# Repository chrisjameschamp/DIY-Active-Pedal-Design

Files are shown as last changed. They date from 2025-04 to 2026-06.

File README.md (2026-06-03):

<h2 align="center">DIY Active Pedal Design</h2>

<p align="center">
  The basic design files for my work-in-progress DIY Active Pedal.
  The majority of these parts are designed to be 3D printed.
  This project is intended to complement the much larger scale project of
  <a href="https://github.com/ChrGri" target="_blank">ChrGri</a>'s
  <a href="https://github.com/ChrGri/DIY-Sim-Racing-FFB-Pedal" target="_blank">
    DIY-Sim-Racing-FFB-Pedal
  </a>.
</p>
<div align="center">
  
  
  
  
  
  
  
  
  

</div>
<div align="center">
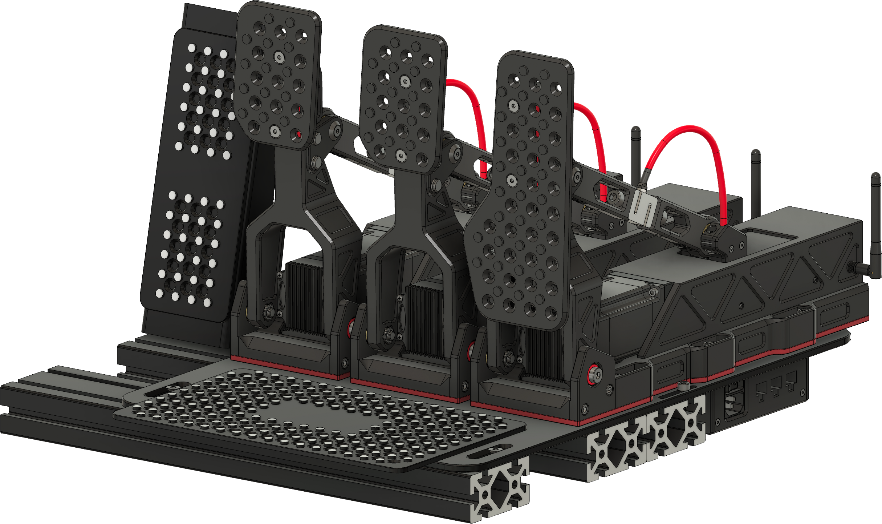
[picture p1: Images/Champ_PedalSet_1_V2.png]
Header
  
</div>

## What This Repo Includes

This repository contains the mechanical design files and build documentation for the DIY Active Pedal hardware:

- STL and STEP files for the printable and machinable pedal components
- Wiki-based build instructions, hardware references, and print guidance
- Design-file README pages for the major assemblies

This project is designed to work with the broader [DIY-Sim-Racing-FFB-Pedal](https://github.com/ChrGri/DIY-Sim-Racing-FFB-Pedal) ecosystem and the [DIY-Sim-Racing-FFB-Pedal-PCBs](https://github.com/gilphilbert/DIY-Sim-Racing-FFB-Pedal-PCBs) by gilphilbert. You will still need the required electronics, firmware/software, power supply, servo motor, linear rail, load cell, wiring, hardware, and appropriate fabrication tools to complete a working pedal.

## What Makes These Pedals Different?

Traditional sim racing pedals use springs, rubber dampers, or load cells to simulate resistance. This project takes things further by using a high-torque servo motor and a linear rail system to deliver real, programmable force feedback directly through the pedal.

What does that mean in practice?

- Feel ABS lockup through the brake pedal  
- Experience throttle kick during gear shifts or traction loss  
- Sense road texture and bumps through the pedal face  
- Adjust pedal weight, travel, and pressure curves entirely in software  
- Create and switch between custom pedal profiles for different cars

These pedals don’t just measure your input — they push back, dynamically responding to what’s happening in the simulation. Whether you’re locking up into a braking zone or driving over rumble strips, the pedals provide responsive, physical feedback.

If you're aiming to build a sim racing setup that closely mirrors a real race car experience, this project is designed to help you get there.

## Documentation

Want to build this project?  
Be sure to check out the [📖 Project Wiki](https://github.com/ChrisJamesChamp/DIY-Active-Pedal-Design/wiki/00-%E2%80%90-DIY-Active-Pedal-Build-Wiki) for:

- Print settings & material recommendations  
- Hardware lists  
- Step-by-step assembly guides 

## License

These 3D design files are licensed under a [Creative Commons BY-NC-SA 4.0 License](https://creativecommons.org/licenses/by-nc-sa/4.0/).

You may:
- Use and remix these files for **personal, non-commercial purposes**.
- Share modified versions, as long as they are also non-commercial, include credit, and use the **same license**.

You may NOT:
- Use these files or derivatives **for commercial use**.
- Re-license modified versions under more restrictive or proprietary terms.

Please credit **@ChrisJamesChamp** and link back to this repository if you use, remix, or share these designs.

##

> ⚠️ **Use at Your Own Risk**
> These design files and instructions are provided for educational and personal-use purposes only.  
> By choosing to build or modify this DIY active pedal system, you acknowledge that:
> 
> - These pedals are powered by **motorized servos**, capable of applying significant mechanical force.
> - The power supply assembly involves **AC mains voltage**, which can cause electric shock, fire, equipment damage, or serious injury if wired incorrectly.
> - Improper assembly, use, or configuration may result in **injury**, **equipment damage**, or **malfunction**.
> - You are solely responsible for ensuring **safe construction**, **appropriate materials**, and **secure electronics**.
> - I (ChrisJamesChamp) accept **no liability** for any injury, loss, or damage arising from use of these files or any derivatives thereof.
>
> **Please take all appropriate safety precautions** when working with powered mechanical and electrical systems.

##

<div align="center">
  
</div>

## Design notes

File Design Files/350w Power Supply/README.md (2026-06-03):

<h2 align="center">DIY Active Pedal Design - 350w Power Supply</h2>

<div align="center">
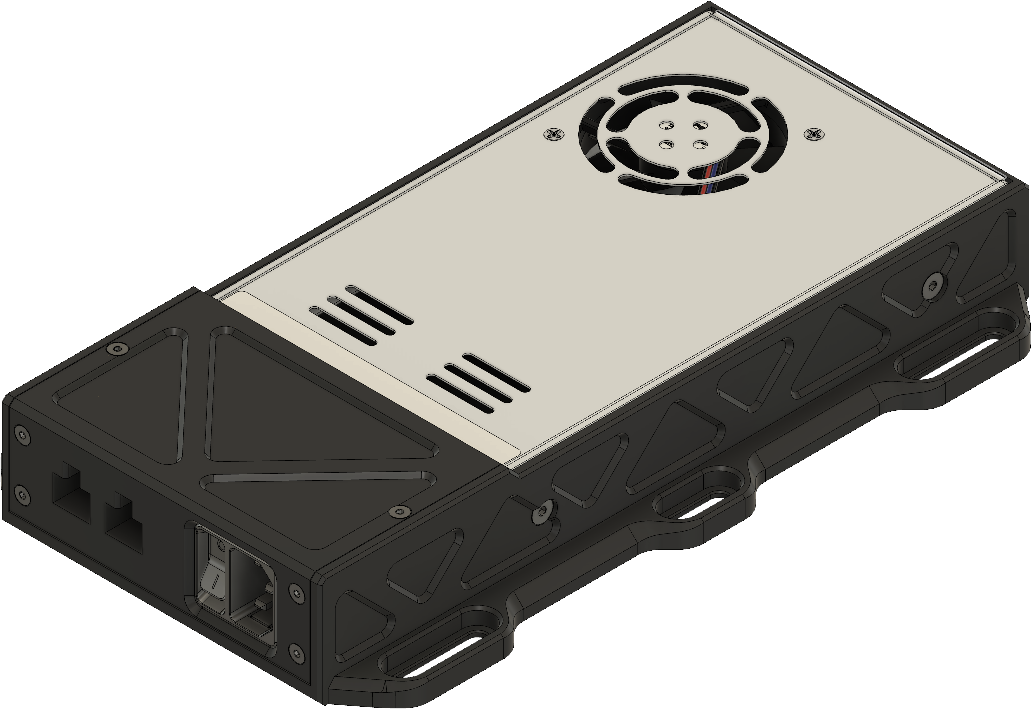
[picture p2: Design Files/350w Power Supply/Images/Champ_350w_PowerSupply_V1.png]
Header
  
</div>

## Index

- [Design](#design)
- [Print Settings](#print-settings)
- [Hardware](#hardware)
  - [Hardware List](#hardware-list)
- [Assembly](#assembly)
- [License](#license)

## Design

This power supply enclosure is completely optional to build, but it adds a few nice features: it hides the power connections, includes a power switch, and uses a standardized cable configuration that’s safe and easy to work with.

The enclosure is built around the [MEANWELL LRS-350-36](https://www.omc-stepperonline.com/lrs-350-36-mean-well-350w-36vdc-9-7a-115-230vac-enclosed-switching-power-supply-lrs-350-36). Other power supplies may work, but dimensions and specs may vary — proceed at your own risk if substituting.

This particular power supply can be used with one or two pedals.  If you are using three pedals you should use the [600w Power Supply](https://github.com/chrisjameschamp/DIY-Active-Pedal-Design/tree/main/Design%20Files/600w%20Power%20Supply) instead.

### Print Settings

This enclosure was printed on a Creality K2 Plus, but your settings will vary depending on the printer and material used. Make sure your filament is well-tuned before printing — the enclosure is large and takes time to complete.

**⚠️ Note:** The main body of the enclosure is just over **280mm wide** and may not fit on most printers. I’ve included a split version that should work on smaller beds. I haven’t tested it personally, but it should print the same.

#### Recommended Print Settings

- **Wall loops**: At least 4
- **Top layers**: 5
- **Bottom layers**: 4
- **Infill**: 20% sparse gyroid
- **If using rectangular infill**: Use 30% or higher

⚠️ **For nylon:**  
Make sure to dry your filament thoroughly before printing. Even slightly damp nylon can result in poor print quality, weak layer bonding, and rough surfaces.

For bed adhesion, use a 10mm brim and optionally apply glue stick or another adhesive. I used both, and they were essential to prevent warping.

## Hardware

The hardware used can mostly be sourced from [McMaster-Carr](https://www.mcmaster.com/).  
If you're substituting parts from your local hardware store or Amazon, be sure to double-check dimensions — they’re critical for proper fit and function.

### Hardware List

| **Item** | **Part Number** | **Qty** | **Link** |
|---|---|---|---|
| MEANWELL LRS-350-36 | LRS-350-36 | 1 | [Link](https://www.omc-stepperonline.com/lrs-350-36-mean-well-350w-36vdc-9-7a-115-230vac-enclosed-switching-power-supply-lrs-350-36) |
| IEC Connector with Power Switch | 5428N118 | 1 | [Link](https://www.mcmaster.com/5428N118/) |
| 16 Gauge Wire | N/A | As needed | [Link](https://a.co/d/feJ6wWT) |
| M3x0.5mm Heat Set Insert | 94180A333 | 6 | [Link](https://www.mcmaster.com/94180a333/) |
| M3x0.5 14mm Flat Head Screw | 92125A133 | 4 | [Link](https://www.mcmaster.com/92125A133/) |
| M3x0.5 18mm Flat Head Screw | 92125A135 | 2 | [Link](https://www.mcmaster.com/92125A135/) |
| M4x0.7 10mm Flat Head Screw | 92125A190 | 8 | [Link](https://www.mcmaster.com/92125A190/) |
| 6 Pin PCIe Extension Cable | N/A | 2 | [Link](https://a.co/d/cVutRBN) |

### Notes

1. **M4x0.7 10mm Flat Head Screw** – These should not be longer than 10mm; anything longer could damage the unit.
2. **PCIe Extension Cables** – The 350w PSU enclosure uses **2** PCIe extension cables. Additional pedal-side PCIe cables are counted separately.

## Assembly

A complete walkthrough of the assembly process can be found on the [Wiki](https://github.com/chrisjameschamp/DIY-Active-Pedal-Design/wiki/03-%E2%80%90-Power-Supply-Unit)

## License

These 3D design files are licensed under a [Creative Commons BY-NC-SA 4.0 License](https://creativecommons.org/licenses/by-nc-sa/4.0/).

You may:
- Use and remix these files for **personal, non-commercial purposes**.
- Share modified versions, as long as they are also non-commercial, include credit, and use the **same license**.

You may NOT:
- Use these files or derivatives **for commercial use**.
- Re-license modified versions under more restrictive or proprietary terms.

Please credit **@ChrisJamesChamp** and link back to this repository if you use, remix, or share these designs.

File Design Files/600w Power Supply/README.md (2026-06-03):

<h2 align="center">DIY Active Pedal Design - 600w Power Supply</h2>

<div align="center">
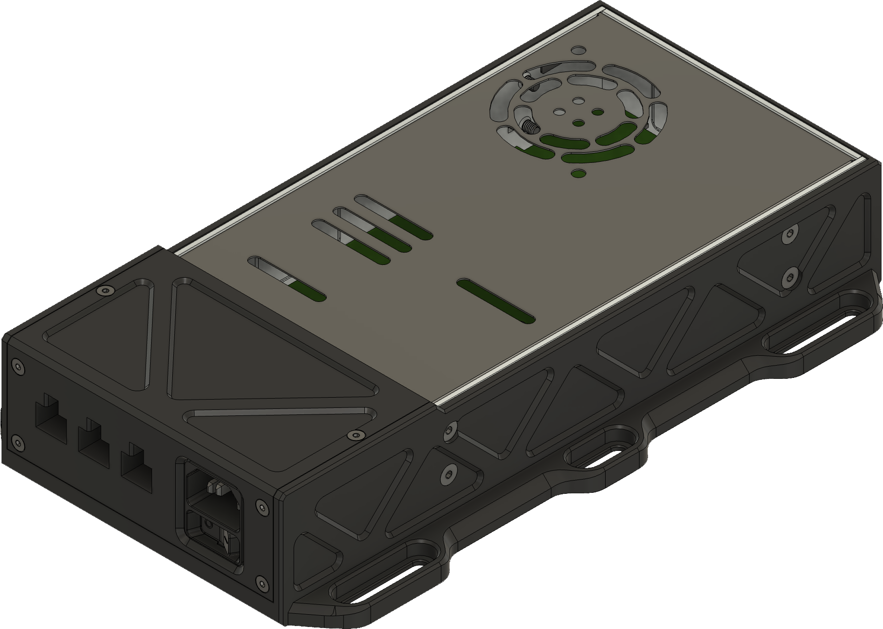
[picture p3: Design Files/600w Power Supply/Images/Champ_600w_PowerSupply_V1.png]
Header
  
</div>

## Index

- [Design](#design)
- [Print Settings](#print-settings)
- [Hardware](#hardware)
  - [Hardware List](#hardware-list)
- [Assembly](#assembly)
- [License](#license)

## Design

This power supply enclosure is completely optional to build, but it adds a few nice features: it hides the power connections, includes a power switch, and uses a standardized cable configuration that’s safe and easy to work with.

The enclosure is built around the [MEANWELL LRS-600-36](https://www.omc-stepperonline.com/lrs-600-36-mean-well-597-6w-36vdc-16-6a-115-230vac-enclosed-switching-power-supply-lrs-600-36). Other power supplies may work, but dimensions and specs may vary — proceed at your own risk if substituting.

This particular power supply can be used with up to three pedals.  However the 600w PSU might be a bit overkill for one or two pedals; consider using the [350w Power Supply](https://github.com/chrisjameschamp/DIY-Active-Pedal-Design/tree/main/Design%20Files/350w%20Power%20Supply) instead.

### Print Settings

This enclosure was printed on a Creality K2 Plus, but your settings will vary depending on the printer and material used. Make sure your filament is well-tuned before printing — the enclosure is large and takes time to complete.

**⚠️ Note:** The main body of the enclosure is just over **280mm wide** and may not fit on most printers. I’ve included a split version that should work on smaller beds. I haven’t tested it personally, but it should print the same.

#### Recommended Print Settings

- **Wall loops**: At least 4
- **Top layers**: 5
- **Bottom layers**: 4
- **Infill**: 20% sparse gyroid
- **If using rectangular infill**: Use 30% or higher

⚠️ **For nylon:**  
Make sure to dry your filament thoroughly before printing. Even slightly damp nylon can result in poor print quality, weak layer bonding, and rough surfaces.

For bed adhesion, use a 10mm brim and optionally apply glue stick or another adhesive. I used both, and they were essential to prevent warping.

## Hardware

The hardware used can mostly be sourced from [McMaster-Carr](https://www.mcmaster.com/).  
If you're substituting parts from your local hardware store or Amazon, be sure to double-check dimensions — they’re critical for proper fit and function.

### Hardware List

| **Item** | **Part Number** | **Qty** | **Link** |
|---|---|---|---|
| MEANWELL LRS-600-36 | LRS-600-36 | 1 | [Link](https://www.omc-stepperonline.com/lrs-600-36-mean-well-597-6w-36vdc-16-6a-115-230vac-enclosed-switching-power-supply-lrs-600-36) |
| IEC Connector with Power Switch | 5428N111 | 1 | [Link](https://www.mcmaster.com/5428N111/) |
| 16 Gauge Wire | N/A | As needed | [Link](https://a.co/d/feJ6wWT) |
| M3x0.5mm Heat Set Insert | 94180A333 | 6 | [Link](https://www.mcmaster.com/94180a333/) |
| M3x0.5 14mm Flat Head Screw | 92125A133 | 4 | [Link](https://www.mcmaster.com/92125A133/) |
| M3x0.5 18mm Flat Head Screw | 92125A135 | 2 | [Link](https://www.mcmaster.com/92125A135/) |
| M4x0.7 10mm Flat Head Screw | 92125A190 | 10 | [Link](https://www.mcmaster.com/92125A190/) |
| 6 Pin PCIe Extension Cable | N/A | 3 | [Link](https://a.co/d/cVutRBN) |

### Notes

1. **M4x0.7 10mm Flat Head Screw** – These should not be longer than 10mm; anything longer could damage the unit.
2. **PCIe Extension Cables** – The 600w PSU enclosure uses **3** PCIe extension cables. Additional pedal-side PCIe cables are counted separately.

## Assembly

A complete walkthrough of the assembly process can be found on the [Wiki](https://github.com/chrisjameschamp/DIY-Active-Pedal-Design/wiki/03-%E2%80%90-Power-Supply-Unit)

## License

These 3D design files are licensed under a [Creative Commons BY-NC-SA 4.0 License](https://creativecommons.org/licenses/by-nc-sa/4.0/).

You may:
- Use and remix these files for **personal, non-commercial purposes**.
- Share modified versions, as long as they are also non-commercial, include credit, and use the **same license**.

You may NOT:
- Use these files or derivatives **for commercial use**.
- Re-license modified versions under more restrictive or proprietary terms.

Please credit **@ChrisJamesChamp** and link back to this repository if you use, remix, or share these designs.

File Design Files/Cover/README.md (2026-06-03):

<h2 align="center">DIY Active Pedal Design - Cover</h2>
<div align="center">
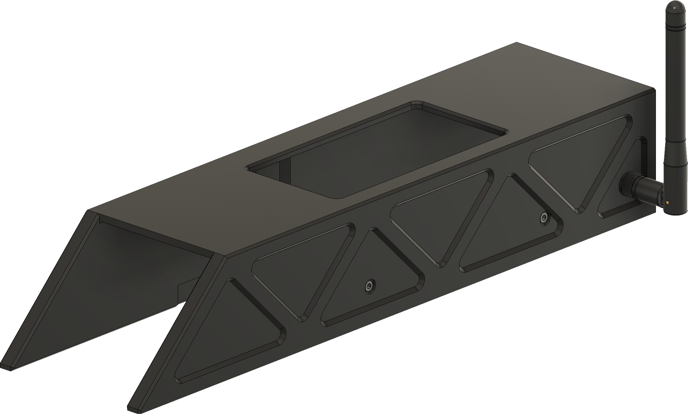
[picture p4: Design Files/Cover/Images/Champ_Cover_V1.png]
Header
  
</div>

## Index

- [Design](#design)
- [3D Printing](#3d-printing)
   - [Material Options](#material-options)
   - [Print Settings](#print-settings)
- [Hardware](#hardware)
   - [Hardware List](#hardware-list)
- [Assembly](#assembly)
- [License](#license)

## Design

The cover is more aesthetics than anything, however it is helpful in reducing the amount of dust and debris that will get into the linear rail which needs to stay clean and lubricated.

## 3D Printing

The cover is designed to be 3d printed, it could be CNC machined as well, although it would probably not be super easy and/or cheap.  If it were to be CNC machined however, there are a lot of areas that could be simplified or adjusted with drill taps to eliminate the use of some hardware.

### Material Options

I’ve only tested this part printed in [Fiberon's PETG-CF](https://a.co/d/dX2OyLc).

The **Cover** is not structural and does not need to be printed in nylon.

### Print Settings

The cover was printed on a Creality K2 Plus, but print settings will vary depending on your printer and material.

**⚠️ Note:** The cover is just over **280mm wide** and may not fit on most printers. I’ve included a split version that should work on smaller beds. I haven’t tested it personally, but it should print the same.

#### Recommended Print Settings

- **Wall loops**: At least 3
- **Top layers**: 4
- **Bottom layers**: 3
- **Infill**: 15% sparse gyroid
- **If using rectangular infill**: Use 20% or higher

## Hardware

The hardware I used can mostly be sourced from [McMaster-Carr](https://www.mcmaster.com/).  
If you're substituting parts from your local hardware store or Amazon, be sure to double-check dimensions — they're critical for fit and function.

### Hardware List

| **Item** | **Part Number** | **Qty** | **Link** |
|---|---|---|---|
| M2.5x0.4 6mm Socket Head Screw  | 91292A010 | 4 | [Link](https://www.mcmaster.com/91292A010/) |
| M3x0.5mm Heat Set Insert | 94180A333 | 2 | [Link](https://www.mcmaster.com/94180A333/) |
| M3x0.5 16mm Socket Head Screw | 91292A115 | 2 | [Link](https://www.mcmaster.com/91292A115/) |
| Coax Antenna Cable | N/A | 1 | [Link](https://a.co/d/crMru0R) |

## Assembly

A complete walkthrough of the assembly process can be found on the [Slider Cover wiki page](https://github.com/chrisjameschamp/DIY-Active-Pedal-Design/wiki/09-%E2%80%90-Slider-Cover).

## License

These 3D design files are licensed under a [Creative Commons BY-NC-SA 4.0 License](https://creativecommons.org/licenses/by-nc-sa/4.0/).

You may:
- Use and remix these files for **personal, non-commercial purposes**.
- Share modified versions, as long as they are also non-commercial, include credit, and use the **same license**.

You may NOT:
- Use these files or derivatives **for commercial use**.
- Re-license modified versions under more restrictive or proprietary terms.

Please credit **@ChrisJamesChamp** and link back to this repository if you use, remix, or share these designs.

##

<div align="center">
  
</div>

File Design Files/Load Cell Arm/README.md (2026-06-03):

<h2 align="center">DIY Active Pedal Design - Load Cell Arm</h2>
<div align="center">
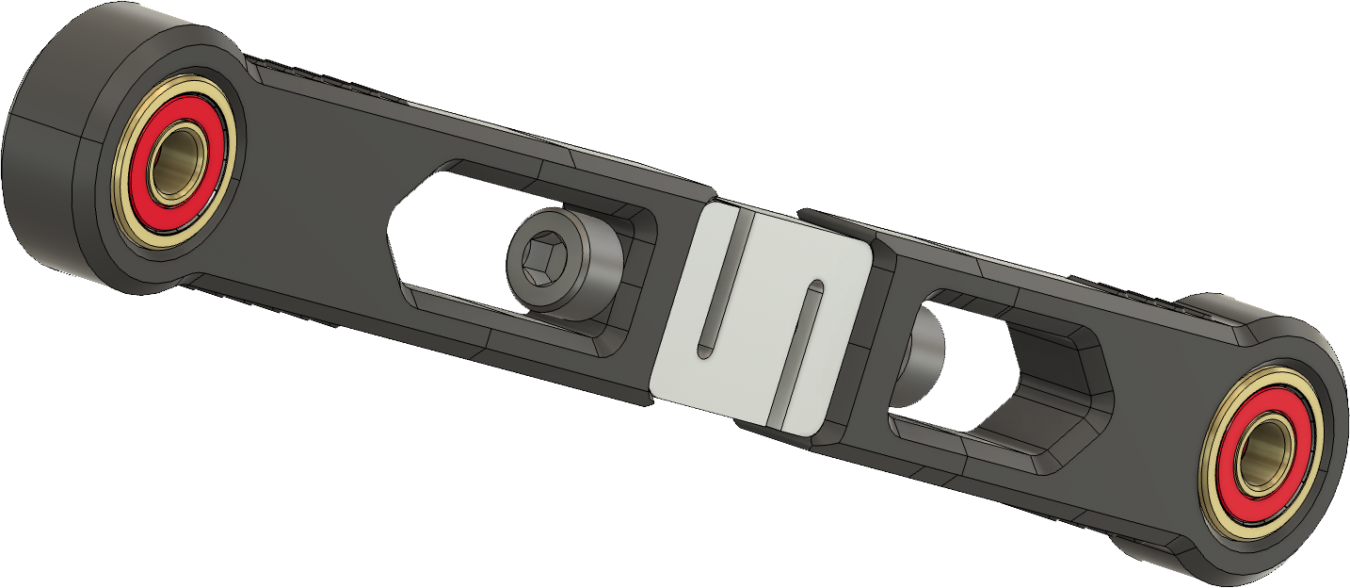
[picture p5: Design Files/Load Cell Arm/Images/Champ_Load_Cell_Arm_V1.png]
Header
  
</div>

## Index

- [Design](#design)
- [3D Printing](#3d-printing)
   - [Material Options](#material-options)
   - [Print Settings](#print-settings)
- [Hardware](#hardware)
   - [Hardware List](#hardware-list)
- [Assembly](#assembly)
- [License](#license)

## Design

The load cell arm connects the pedal arm to the slider and is the primary component for transferring forces between the pedal arm and the servo motor.

## 3D Printing

The arm is designed to be 3D printed, though it is one of the few parts that would **greatly benefit** from being CNC machined due to the forces involved.

### Material Options

This part has only been tested using [Fiberon's PPS-CF](https://a.co/d/0nK6oxm).

While PPS is known for its **high temperature resistance**, it also offers excellent stiffness with minimal deformation, making it ideal for this application. Nylon may work, but it tends to flex more under load. Less deformation in this part means more accurate and precise force transfer to the load cell.

### Print Settings

The arm was printed on a Creality K2 Plus, but settings may vary depending on your printer and chosen material.

#### Recommended Print Settings

- **Wall loops**: At least 10
- **Top layers**: 12
- **Bottom layers**: 10
- **Infill**: 30% sparse gyroid
- **If using rectangular infill**: Use 40% or higher

⚠️ For PPS:
Thoroughly dry your filament before printing. Even slightly damp PPS will print poorly, resulting in weak layer adhesion and rough surface quality.

## Hardware

The hardware I used can mostly be sourced from [McMaster-Carr](https://www.mcmaster.com/).  
If you're substituting parts from your local hardware store or Amazon, be sure to double-check dimensions — they're critical for fit and function.

### Hardware List

| **Item** | **Part Number** | **Qty** | **Link** |
|---|---|---|---|
| Pressure Sensor S Load Cell Weight Sensor(200KG) | DYLY-107 | 1 | [Link](https://a.co/d/eEIK39s) |
| M8x1.25 18mm Socket Head Cap Screw | 91292A080  | 2 | [Link](https://www.mcmaster.com/91292A080/) |
| 608ZZ Bearing | 608ZZ | 4 | [Link](https://a.co/d/8xCCTFy) |

### Notes

1. **Pressure Sensor** – I used the 200KG variant, which is the highest recommended. Anything between 100KG and 200KG should work well depending on your force preference.

## Assembly

A complete walkthrough of the assembly process can be found on the [Load Cell Arm wiki page](https://github.com/chrisjameschamp/DIY-Active-Pedal-Design/wiki/07-%E2%80%90-Load-Cell-Arm).

## License

These 3D design files are licensed under a [Creative Commons BY-NC-SA 4.0 License](https://creativecommons.org/licenses/by-nc-sa/4.0/).

You may:
- Use and remix these files for **personal, non-commercial purposes**.
- Share modified versions, as long as they are also non-commercial, include credit, and use the **same license**.

You may NOT:
- Use these files or derivatives **for commercial use**.
- Re-license modified versions under more restrictive or proprietary terms.

Please credit **@ChrisJamesChamp** and link back to this repository if you use, remix, or share these designs.

##

<div align="center">
  
</div>

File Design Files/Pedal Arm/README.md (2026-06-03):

<h2 align="center">DIY Active Pedal Design - Pedal Arm</h2>
<div align="center">
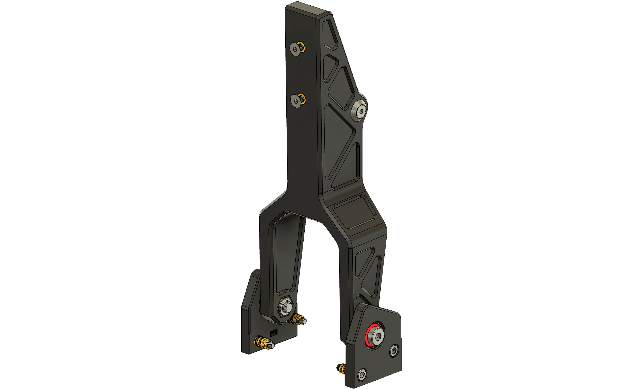
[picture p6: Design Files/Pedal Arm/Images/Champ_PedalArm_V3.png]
Header
  
</div>

## Index

- [Design](#design)
- [3D Printing](#3d-printing)
   - [Material Options](#material-options)
   - [Print Settings](#print-settings)
- [Hardware](#hardware)
   - [Hardware List](#hardware-list)
- [Assembly](#assembly)
- [License](#license)

## Design

This is the third design iteration of the Pedal Arm. The first version had mounting brackets approximately 25mm lower, which increased travel but reduced usable servo force. Since that much travel isn’t necessary, the brackets were moved upward in later revisions — nearly doubling the effective braking force the servos can handle. The current version also includes additional stiffness improvements over the earlier arms.

## 3D Printing

The arm is designed to be 3d printed, it could be CNC machined as well, although it would probably not be super easy and/or cheap.  If it were to be CNC machined however, there are a lot of areas that could be simplified or adjusted with drill taps to eliminate the use of some hardware.

### Material Options

I’ve only tested this part printed in eSun’s [ePA-CF](https://a.co/d/0XDH10W), an 80/20 nylon-carbon fiber composite with excellent strength, layer adhesion, and added rigidity from the carbon fiber. It also has relatively high tensile strength.

You could try pure nylon, although it might be too flexible.

More affordable options like PETG+CF or ABS+CF composites may work as well. While they likely have enough strength in the XY axis (which is how the part is oriented for printing), I’m less confident in their Z-axis strength due to weaker layer bonding.

Some users in the DIY FFB Pedal Discord have reported success with PLA+ or regular PETG. I haven’t tested these myself, and I’d be cautious about PLA+’s long-term durability.

### Print Settings

The pedal arm was printed on a Creality K2 Plus, but print settings will vary depending on your printer and material. Make sure your filament and printer are well-tuned before attempting a full print — it’s a large part and can take quite a while.

Don’t do what I did and print seven of them while dialing in settings 😅

#### Recommended Print Settings

- **Wall loops**: At least 10
- **Top layers**: 12
- **Bottom layers**: 10
- **Infill**: 30% sparse gyroid
- **If using rectangular infill**: Use 40% or higher

⚠️ For nylon:
Thoroughly dry your filament before printing. Even slightly damp nylon will print poorly, resulting in weak layer adhesion and rough surface quality.

Due to the high wall/infill density, use a brim (10mm recommended) and possibly glue stick or other adhesion aid. I used both, and they were necessary to prevent warping.

## Hardware

The hardware I used can mostly be sourced from [McMaster-Carr](https://www.mcmaster.com/).  
If you're substituting parts from your local hardware store or Amazon, be sure to double-check dimensions — they're critical for fit and function.

### Hardware List

| **Item** | **Part Number** | **Qty** | **Link** |
|---|---|---|---|
| M8x1.25 25mm Hex Cap Head Screw | 92095A286 | 2 | [Link](https://www.mcmaster.com/92095A286/) |
| M8 Nylon Locking Nut | 93625A300 | 2 | [Link](https://www.mcmaster.com/93625A300/) |
| M5x0.8mm Heat Set Insert | 94180A363 | 6 | [Link](https://www.mcmaster.com/94180A363/) |
| M3 Square Nut | 97258A101 | 2 | [Link](https://www.mcmaster.com/97258A101/) |
| M5x0.8 14mm Socket Head Screw | 91292A058 | 4 | [Link](https://www.mcmaster.com/91292A058/) |
| M3x0.5 16mm Flat Head Screw | 92125A134 | 2 | [Link](https://www.mcmaster.com/92125A134/) |
| M5x0.8 16mm Flat Head Screw | 92125A212 | 2 | [Link](https://www.mcmaster.com/92125A212/) |
| M5 Steel Finish Washer | 98472A300 | 2 | [Link](https://www.mcmaster.com/98472A300/) |
| M5x0.8 12mm Flat Head Screw | 92125A210 | 2 | [Link](https://www.mcmaster.com/92125A210/) |
| 8mm OD, 4.2mm ID, 30mm Spacer | 92871A212 | 1 | [Link](https://www.mcmaster.com/92871A212/) |
| 608ZZ Bearing | 608ZZ | 2 | [Link](https://a.co/d/8xCCTFy) |

### Notes

1. **M5x0.8mm Heat Set Insert** – The side mounts use 4 x M5x0.8mm Heat Set Insert. The front-facing holes of the pedal arm use 2 x M5x0.8mm Heat Set Insert.
2. **8mm OD Spacer** – This needs to be **tapped on both sides** for M5x0.8 threads.

## Assembly

Complete walkthroughs of the assembly process can be found on the [Pedal Arm wiki page](https://github.com/chrisjameschamp/DIY-Active-Pedal-Design/wiki/06-%E2%80%90-Pedal-Arm) and [Arm Connection wiki page](https://github.com/chrisjameschamp/DIY-Active-Pedal-Design/wiki/10-%E2%80%90-Arm-Connection).

## License

These 3D design files are licensed under a [Creative Commons BY-NC-SA 4.0 License](https://creativecommons.org/licenses/by-nc-sa/4.0/).

You may:
- Use and remix these files for **personal, non-commercial purposes**.
- Share modified versions, as long as they are also non-commercial, include credit, and use the **same license**.

You may NOT:
- Use these files or derivatives **for commercial use**.
- Re-license modified versions under more restrictive or proprietary terms.

Please credit **@ChrisJamesChamp** and link back to this repository if you use, remix, or share these designs.

##

<div align="center">
  
</div>

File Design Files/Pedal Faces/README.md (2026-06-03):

<h2 align="center">DIY Active Pedal Design - Pedal Faces</h2>
<div align="center">
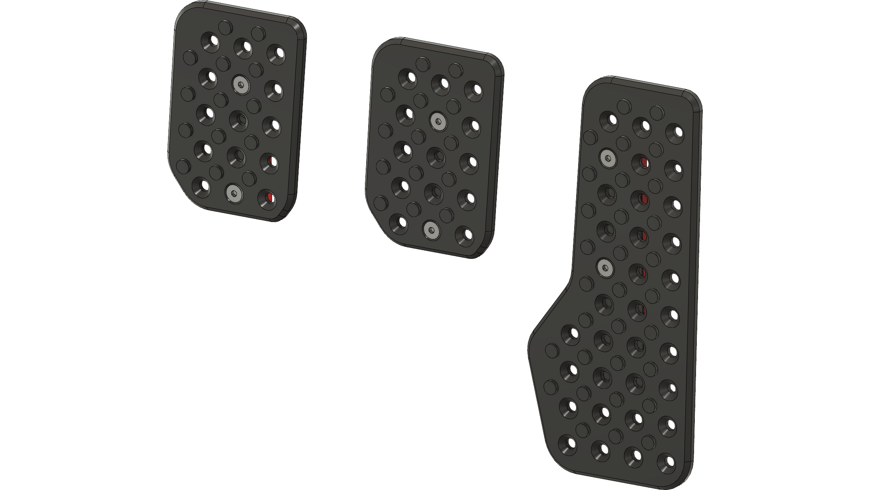
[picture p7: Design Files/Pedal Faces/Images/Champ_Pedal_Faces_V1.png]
Header
  
</div>

## Index

- [Design](#design)
- [3D Printing](#3d-printing)
   - [Material Options](#material-options)
   - [Print Settings](#print-settings)
- [Hardware](#hardware)
   - [Hardware List](#hardware-list)
- [Assembly](#assembly)
- [License](#license)

## Design

The pedal faces are designed to match my existing dead pedal and heel plate from [Pedal Haus](http://www.pedalhaus.com), which produces pedals and accessories for most BMW models.  
Each pedal face consists of **three parts**: the faceplate, the mounting bracket, and a cosmetic beauty ring.

There are two distinct pedal face shapes and three mounting brackets. The **throttle pedal** is larger and uses its own mounting bracket. The **brake and clutch pedals** share the same face, but use different mounting brackets. This difference ensures that when all three pedal assemblies are mounted equidistant from one another, the spacing between pedals remains visually and functionally consistent.

If you're building only a throttle and brake pedal setup, you can choose either the **brake** or **clutch** bracket for the brake pedal. The **clutch bracket** increases the spacing between the pedals, while the **brake bracket** decreases it.  
Which one you use is entirely a matter of personal preference.

## 3D Printing

These parts are designed for 3D printing, though the faceplates are one of the few components that could benefit significantly from being **CNC machined** for a more polished and professional finish. I eventually plan to machine and anodize mine to match the rest of my Pedal Haus components.

### Material Options

The pedal face has been tested with [Fiberon's PPS-CF](https://a.co/d/0nK6oxm), though it should also work well with eSun’s [ePA-CF](https://a.co/d/0XDH10W).

- **Pedal Mount**: Should be printed in ePA-CF, but PETG-CF is also acceptable.
- **Beauty Ring**: Can be printed in any material — this part is purely cosmetic. I've tested both PLA and PETG, ultimately using PETG due to color preference.

While PPS offers **high temperature resistance** and exceptional stiffness, nylon tends to flex under load. A stiffer material ensures that the pedal feels as rigid and responsive as possible, even though it’s made from plastic.

### Print Settings

The pedal face was printed on a Creality K2 Plus, but your settings may vary based on printer and material.

#### Recommended Print Settings

- **Wall loops**: At least 10
- **Top layers**: 12
- **Bottom layers**: 10
- **Infill**: 30% sparse gyroid
- **If using rectangular infill**: Use 40% or higher

⚠️ For PPS / Nylon:  
Make sure to thoroughly dry your filament before printing. Even slightly damp material will result in poor print quality, weak adhesion, and reduced strength.

## Hardware

Most hardware is sourced from [McMaster-Carr](https://www.mcmaster.com/).  
If substituting from Amazon or local hardware stores, double-check dimensions — tolerances here matter.

The required hardware is the same regardless of which pedal variation you're building.

### Hardware List

| **Item** | **Part Number** | **Qty** | **Link** |
|---|---|---|---|
| M5x0.8mm Thin-Profile Hex Nut | 90710A037 | 2 | [Link](https://www.mcmaster.com/90710A037/) |
| M5x0.8 12mm Flat Head Screw | 92125A210 | 2 | [Link](https://www.mcmaster.com/92125A210/) |

### Notes

1. **12mm Screws** – Screw length is important. A 10mm length may work, but anything longer than 12mm may prevent the faceplate from seating securely.

## Assembly

A complete walkthrough of the assembly process can be found on the [Pedal Faces wiki page](https://github.com/chrisjameschamp/DIY-Active-Pedal-Design/wiki/11-%E2%80%90-Pedal-Faces).

## License

These 3D design files are licensed under a [Creative Commons BY-NC-SA 4.0 License](https://creativecommons.org/licenses/by-nc-sa/4.0/).

You may:
- Use and remix these files for **personal, non-commercial purposes**.
- Share modified versions, as long as they are also non-commercial, include credit, and use the **same license**.

You may NOT:
- Use these files or derivatives **for commercial use**.
- Re-license modified versions under more restrictive or proprietary terms.

Please credit **@ChrisJamesChamp** and link back to this repository if you use, remix, or share these designs.

##

<div align="center">
  
</div>

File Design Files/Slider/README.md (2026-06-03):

<h2 align="center">DIY Active Pedal Design - Slider</h2>
<div align="center">
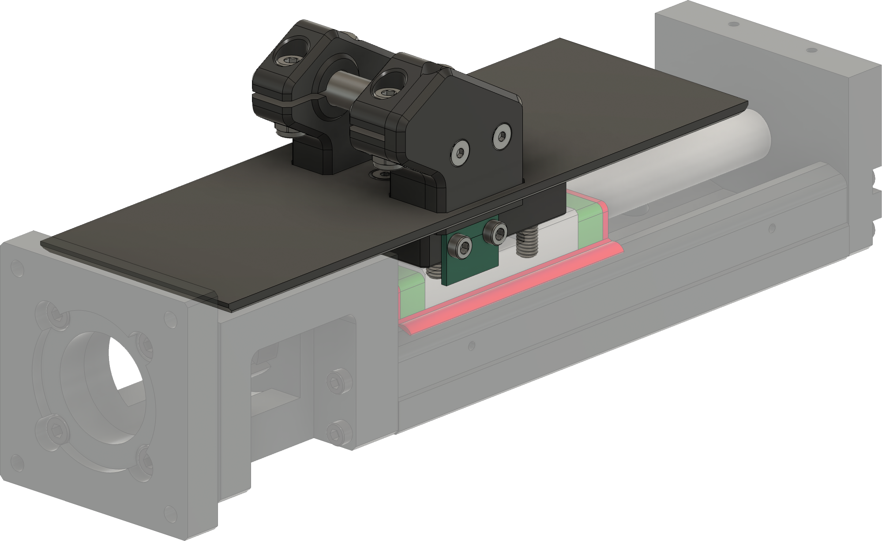
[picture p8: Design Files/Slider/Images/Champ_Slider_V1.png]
Header
  
</div>

## Index

- [Design](#design)
- [3D Printing](#3d-printing)
   - [Material Options](#material-options)
   - [Print Settings](#print-settings)
- [Hardware](#hardware)
   - [Hardware List](#hardware-list)
- [Assembly](#assembly)
- [License](#license)

## Design

The slider is designed to be simple, functional, and easy to assemble.

## 3D Printing

The slider is designed to be 3d printed, it could be CNC machined as well, although it would probably not be super easy and/or cheap.  If it were to be CNC machined however, there are a lot of areas that could be simplified or adjusted with drill taps to eliminate the use of some hardware.

### Material Options

I’ve only tested these parts printed in eSun’s [ePA-CF](https://a.co/d/0XDH10W), an 80/20 nylon-carbon fiber composite with excellent strength, layer adhesion, and added rigidity from the carbon fiber. It also has relatively high tensile strength.

You could try pure nylon, although it might be too flexible.

More affordable options like PETG+CF or ABS+CF composites may work as well. While they likely have enough strength in the XY axis (which is how the part is oriented for printing), I’m less confident in their Z-axis strength due to weaker layer bonding.

Some users in the DIY FFB Pedal Discord have reported success with PLA+ or regular PETG. I haven’t tested these myself, and I’d be cautious about PLA+’s long-term durability.

The **Slider_Shield** is not structural and does not need to be printed in nylon.  I personally printed and tested it with [Fiberon's PETG-CF](https://a.co/d/dX2OyLc).

### Print Settings

The slider was printed on a Creality K2 Plus, but print settings will vary depending on your printer and material.

#### Recommended Print Settings

- **Wall loops**: At least 10
- **Top layers**: 12
- **Bottom layers**: 10
- **Infill**: 30% sparse gyroid
- **If using rectangular infill**: Use 40% or higher

⚠️ For nylon:
Thoroughly dry your filament before printing. Even slightly damp nylon will print poorly, resulting in weak layer adhesion and rough surface quality.

## Hardware

The hardware I used can mostly be sourced from [McMaster-Carr](https://www.mcmaster.com/).  
If you're substituting parts from your local hardware store or Amazon, be sure to double-check dimensions — they're critical for fit and function.

### Hardware List

| **Item** | **Part Number** | **Qty** | **Link** |
|---|---|---|---|
| M3x0.5mm Heat Set Insert | 94180A333 | 2 | [Link](https://www.mcmaster.com/94180A333/) |
| M3x0.5 4mm Socket Head Screw | 91292A109 | 2 | [Link](https://www.mcmaster.com/91292A109/) |
| M3x0.5 8mm Flat Head Screw | 92125A128 | 2 | [Link](https://www.mcmaster.com/92125A128/) |
| M3x0.5 10mm Flat Head Screw | 92125A130 | 2 | [Link](https://www.mcmaster.com/92125A130/) |
| M4x0.7 Standard Nut | 91828A231 | 4 | [Link](https://www.mcmaster.com/91828A231/) |
| M4x0.7 14mm Socket Head Screw | 91292A038 | 2 | [Link](https://www.mcmaster.com/91292A038/) |
| M4x0.7 30mm Socket Head Screw | 91292A130 | 2 | [Link](https://www.mcmaster.com/91292A130/) |
| M5x0.8 16mm Socket Head Screw | 91292A126 | 2 | [Link](https://www.mcmaster.com/91292A126/) |
| M5x0.8 45mm Socket Head Screw | 91292A195 | 2 | [Link](https://www.mcmaster.com/91292A195/) |
| 8mm x 40mm Dowel Pin | 91585A829 | 1 | [Link](https://www.mcmaster.com/91585A829/) |
| FPC FFC PCB Converter Board 6P  | N/A | 1 | [Link](https://a.co/d/bPsciNe) |
| 1/4" Silicone Tubing or PTFE Tubing | N/A | As needed | [Link](https://a.co/d/5qUH8Bg) |
| Heat Shrink Tube | N/A | As needed | N/A |
| Kapton Tape | N/A | As needed | [Link](https://a.co/d/9xGHyLZ) |
| FFC Ribbon Flat Flexible Cable, 6 Pin | N/A | 1 | N/A |

## Assembly

A complete walkthrough of the assembly process can be found on the [Slider wiki page](https://github.com/chrisjameschamp/DIY-Active-Pedal-Design/wiki/08-%E2%80%90-Slider).

## License

These 3D design files are licensed under a [Creative Commons BY-NC-SA 4.0 License](https://creativecommons.org/licenses/by-nc-sa/4.0/).

You may:
- Use and remix these files for **personal, non-commercial purposes**.
- Share modified versions, as long as they are also non-commercial, include credit, and use the **same license**.

You may NOT:
- Use these files or derivatives **for commercial use**.
- Re-license modified versions under more restrictive or proprietary terms.

Please credit **@ChrisJamesChamp** and link back to this repository if you use, remix, or share these designs.

##

<div align="center">
  
</div>

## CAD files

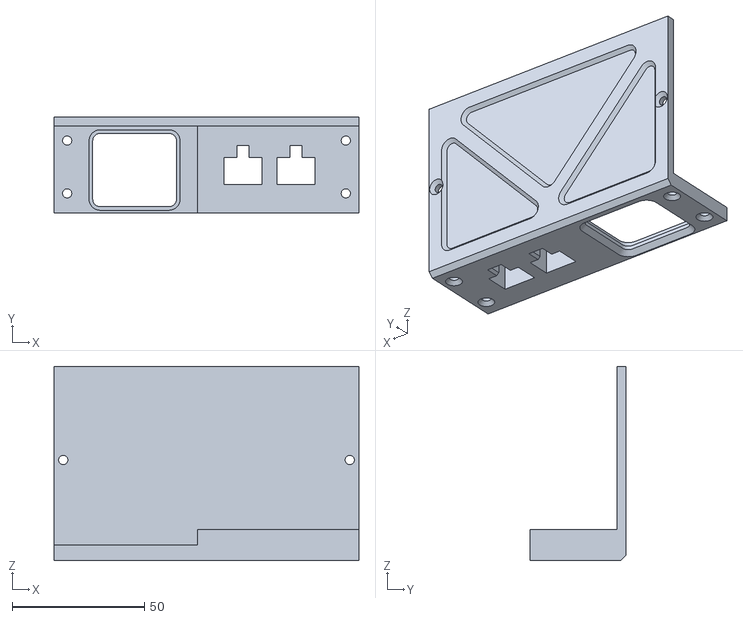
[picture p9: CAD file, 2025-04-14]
Design Files/350w Power Supply/350w_PSU_IoCover_V1.stl
115.5 x 36.5 x 73.5

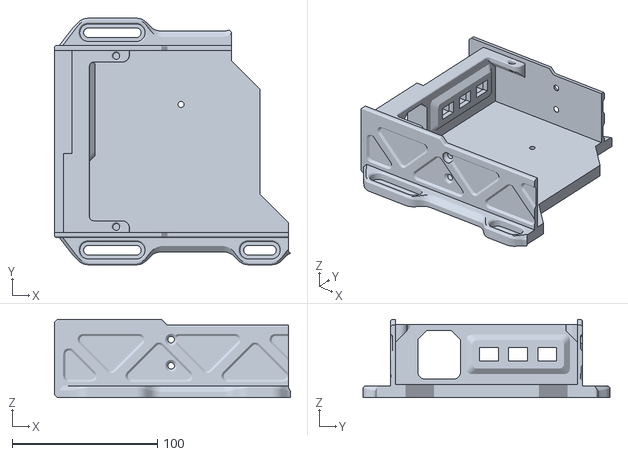
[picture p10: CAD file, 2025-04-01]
Design Files/600w Power Supply/600w_PSU_Case_Front_V1.stl
162.2 x 169.5 x 53.9

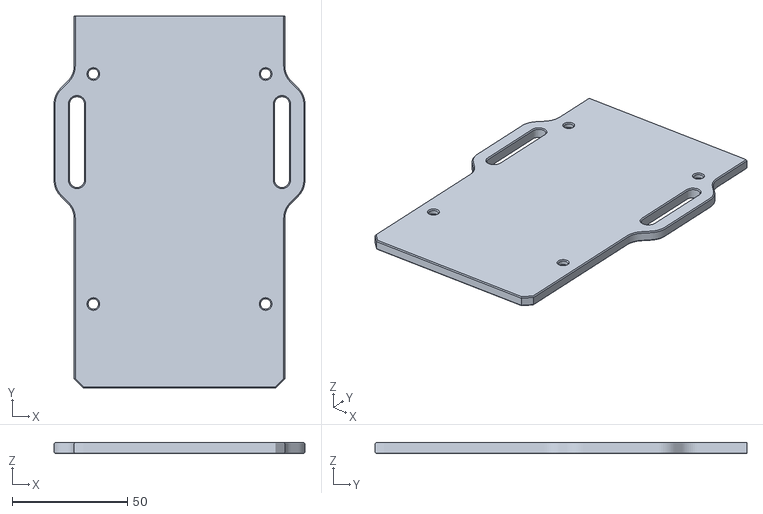
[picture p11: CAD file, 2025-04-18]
Design Files/Base Assembly/Base_Plate_Alt_Rear_V1.stl
109.1 x 161.7 x 4.75

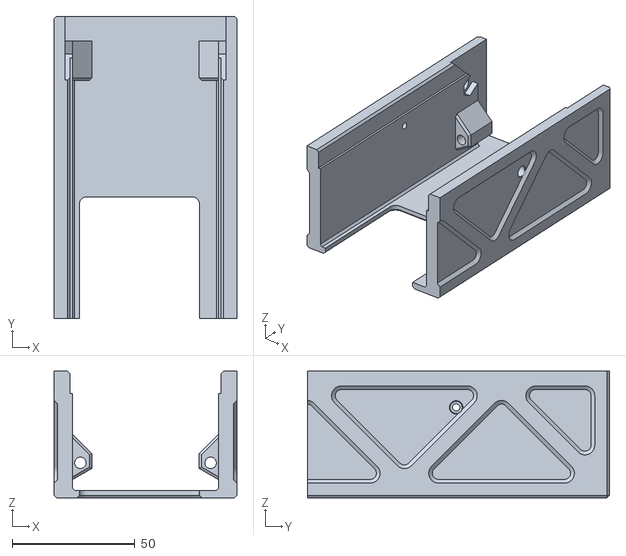
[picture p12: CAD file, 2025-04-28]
Design Files/Cover/Cover_Rear_V1.stl
74.6 x 123.1 x 51.6

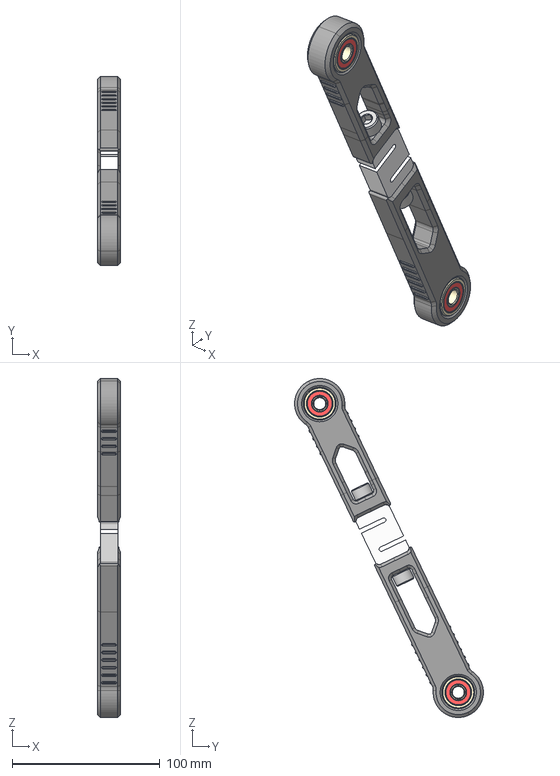
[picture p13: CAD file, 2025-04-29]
Design Files/Load Cell Arm/Load_Cell_Arm_V1.step
15.6 x 127.7 x 229.1 mm
5972K501_Ball Bearing x 4
91292A080_18-8 Stainless Steel Socket Head Screw x 2

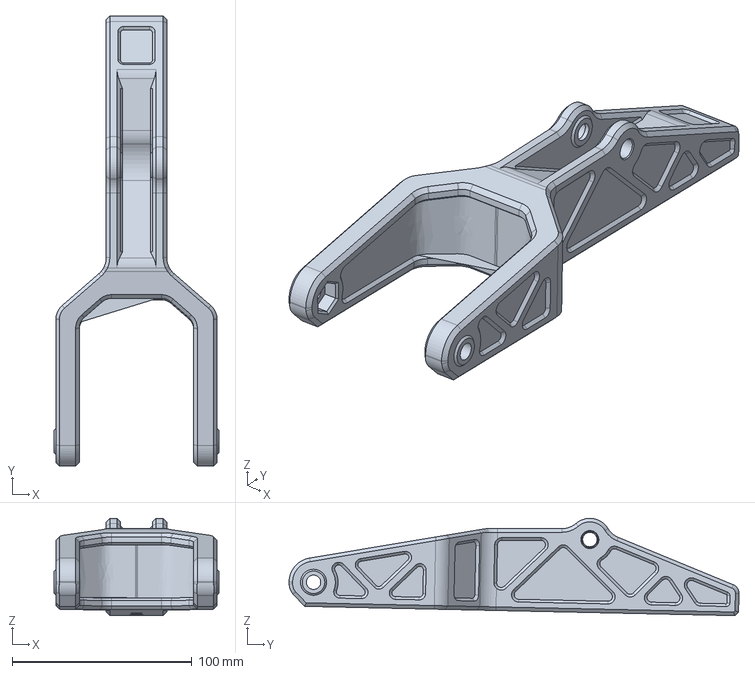
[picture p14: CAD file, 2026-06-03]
Design Files/Pedal Arm/Pedal_Arm_V3.step
91.6 x 250.1 x 54.1 mm

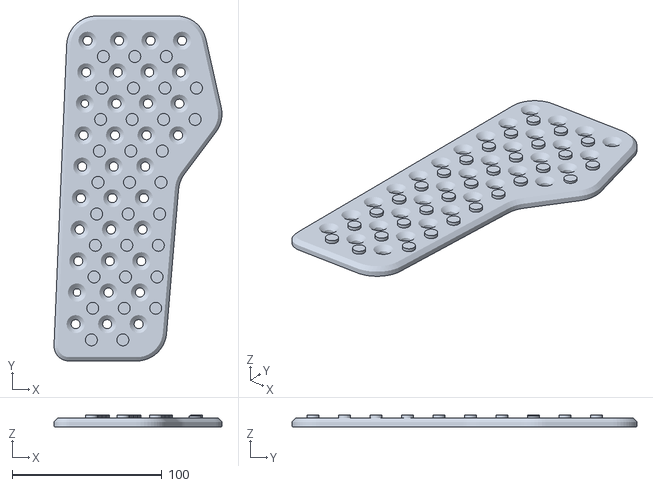
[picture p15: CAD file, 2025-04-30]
Design Files/Pedal Faces/Throttle_Pedal_Face_V1.stl
112.0 x 230.0 x 8.00

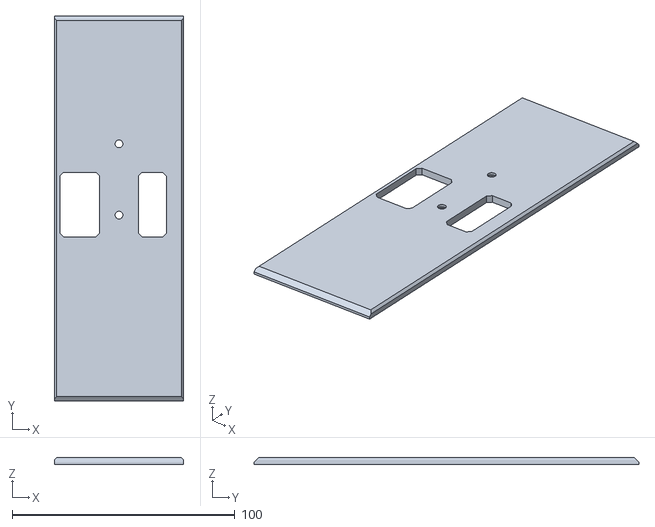
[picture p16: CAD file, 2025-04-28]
Design Files/Slider/Slider_Shield_V1.stl
58.0 x 173.0 x 3.00

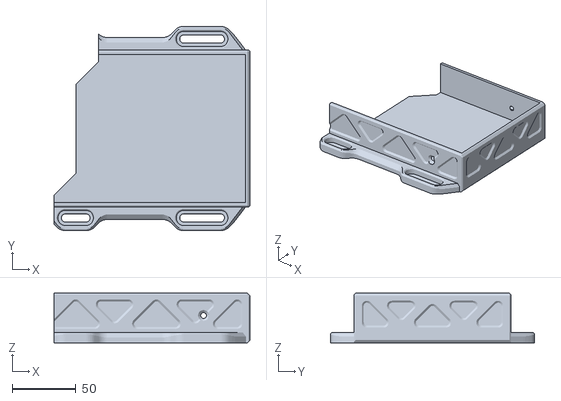
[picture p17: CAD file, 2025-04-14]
Design Files/350w Power Supply/350w_PSU_Case_Rear_V1.stl
153.9 x 160.5 x 38.9

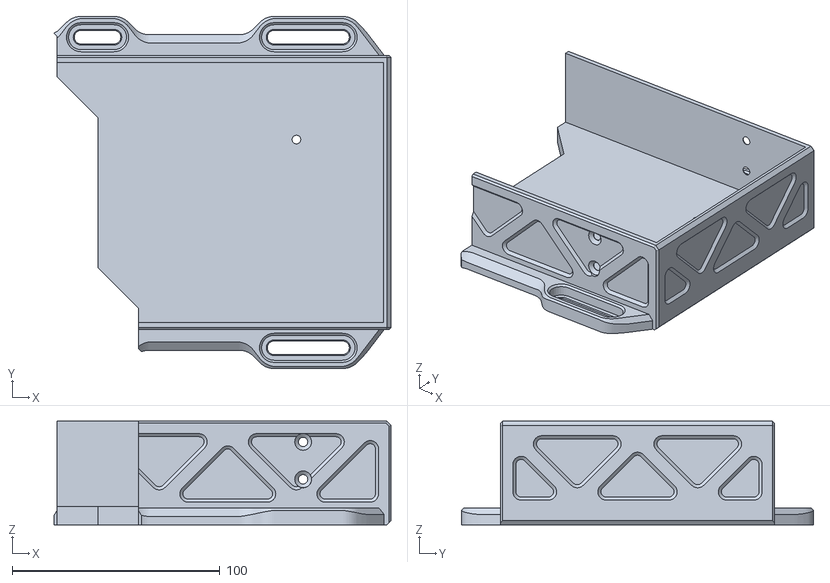
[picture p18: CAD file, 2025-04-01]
Design Files/600w Power Supply/600w_PSU_Case_Rear_V1.stl
162.2 x 169.5 x 49.9

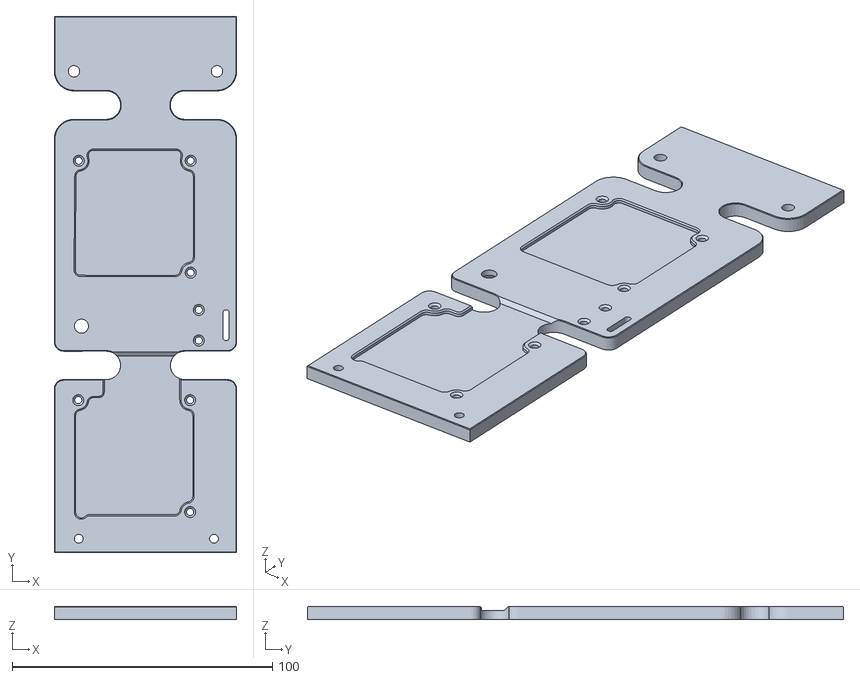
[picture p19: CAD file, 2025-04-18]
Design Files/Base Assembly/Base_PCB_Cover_V1.stl
70.1 x 206.0 x 5.00

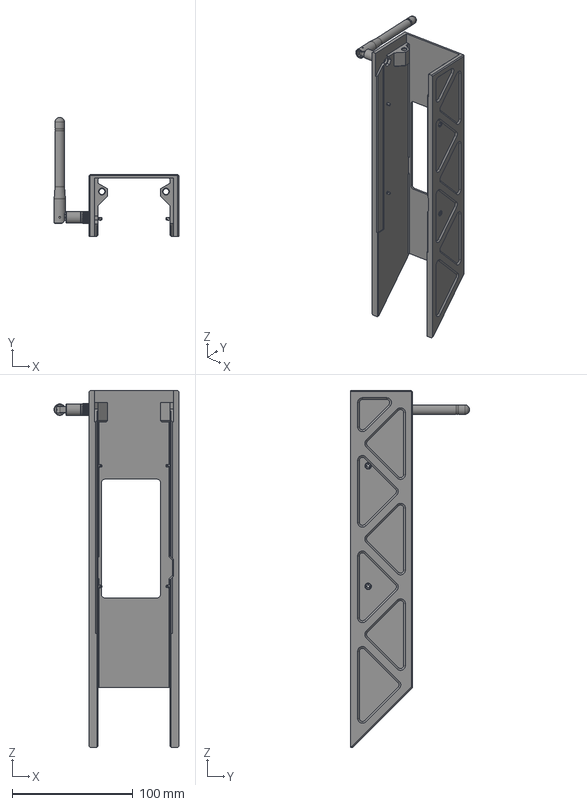
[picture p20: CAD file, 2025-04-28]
Design Files/Cover/Cover_V1.step
103.6 x 98.8 x 296.1 mm
91292A010_18-8 Stainless Steel Socket Head Screw x 2
91292A010_18-8 Stainless Steel Socket Head Screw_1 x 2
Bottom_Radio_Antenna
Top_Radio_Antenna
Screw_Radio_Antenna
Insert_Radio_Antenna
Pin_Radio_Antenna x 2
Wire_Top_Radio_Antenna
Wire_Radio_Antenna

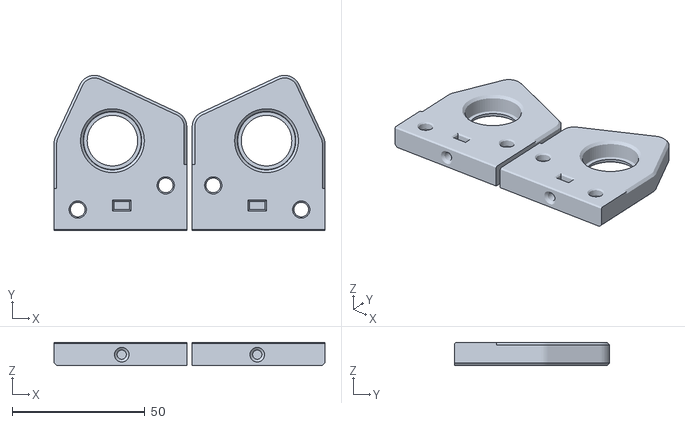
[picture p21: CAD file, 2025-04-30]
Design Files/Pedal Arm/Pedal_Arm_Lower_Brackets_V2.stl
102.0 x 58.5 x 8.75

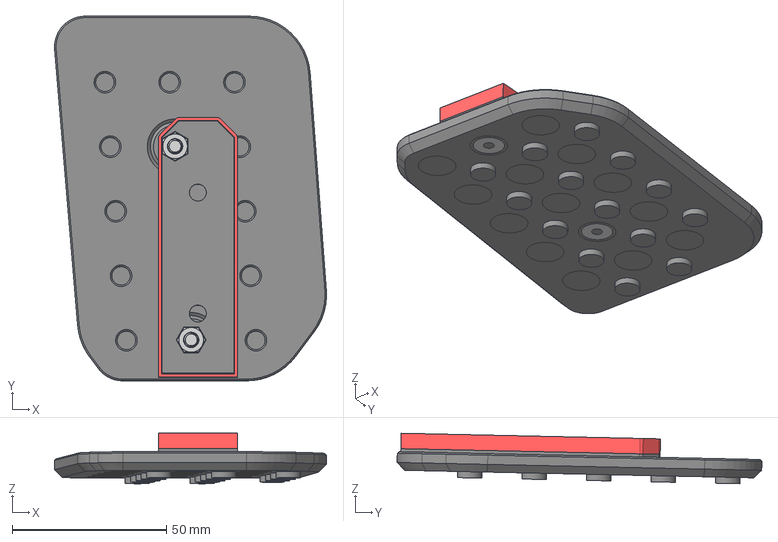
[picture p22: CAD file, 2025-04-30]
Design Files/Pedal Faces/Brake_Pedal_V1.step
88.2 x 118.3 x 16.4 mm
90710A037_18-8 Stainless Steel Thin Hex Nut x 2
92125A210_18-8 Stainless Steel Hex Drive Flat Head Screw x 2

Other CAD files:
Design Files/Slider/Slider_Base_V1.stl
Design Files/350w Power Supply/350w_PSU_Case_Front_V1.stl
Design Files/600w Power Supply/600w_PSU_Case_V1.stl
Design Files/Base Assembly/Base_Front_V1.stl
Design Files/350w Power Supply/350w_PSU_Case_V1.stl
Design Files/600w Power Supply/600w_PSU_IoCover_V1.stl
Design Files/Base Assembly/Base_IO_Bracket_V1.stl
Design Files/Base Assembly/Base_Plate_Alt_Front_V1.stl
Design Files/Base Assembly/Base_Plate_Alt_Mid_V1.stl
Design Files/Base Assembly/Base_Plate_V1.step
Design Files/Base Assembly/Base_Rear_Alt_V1.stl
Design Files/Base Assembly/Base_Rear_Cover_V1.stl
Design Files/Base Assembly/Base_Rear_V1.stl
Design Files/Cover/Cover_Front_V1.stl
Design Files/Cover/Cover_V1.stl
Design Files/Load Cell Arm/Load_Cell_Arm_V1.stl
Design Files/Pedal Arm/Old Versions/Pedal_Arm_Upper_Brackets_V2.stl
Design Files/Pedal Arm/Old Versions/Pedal_Arm_V2.step
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

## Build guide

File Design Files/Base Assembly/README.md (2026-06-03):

<h2 align="center">DIY Active Pedal Design - Base Assembly</h2>
<div align="center">
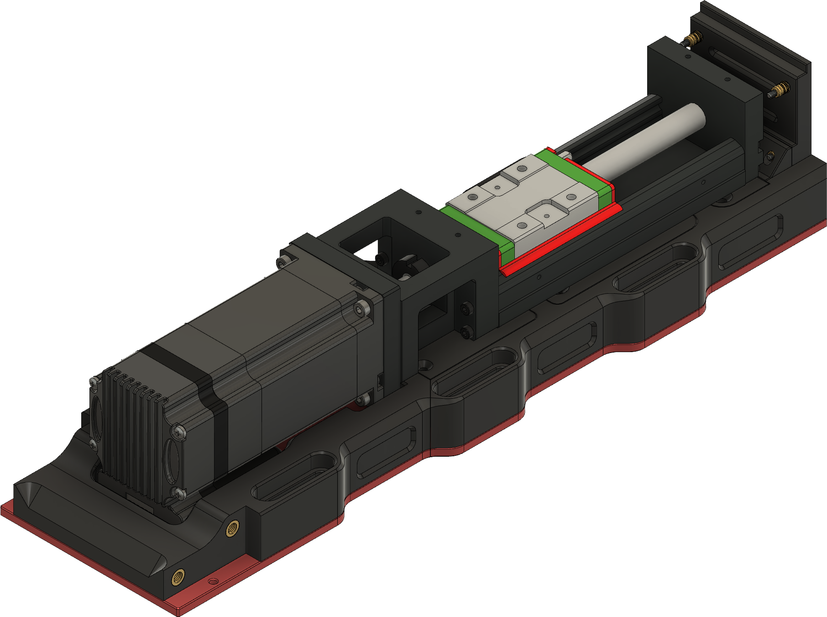
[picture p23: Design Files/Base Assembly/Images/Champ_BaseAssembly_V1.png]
Header
  
</div>

## Index

- [Design](#design)
- [Print Settings](#print-settings)
- [Machined Parts](#machined-parts)
- [Hardware](#hardware)
  - [Hardware List](#hardware-list)
- [Assembly](#assembly)
- [License](#license)

## Design

The base assembly is the most critical component of the pedal system and houses the majority of mechanical and electronic elements.

It’s built around the [JLCPCB Linear Actuator (JKK60-5-P-150-A1-F4-M)](https://jlcmc.com/product/s/B16/BQD-JKK60/FA-%E7%9B%B4%E7%BA%BF%E8%BF%90%E5%8A%A8%E9%9B%B6%E4%BB%B6-%E9%92%A2%E5%88%B6%E7%9B%B4%E7%BA%BF%E6%A8%A1%E7%BB%84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) and the [iSV57T-130S 130W NEMA 23 Servo Motor](https://www.omc-stepperonline.com/nema-23-integrated-easy-servo-motor-130w-3000rpm-0-45nm-63-73oz-in-20-50vdc-servo-motor-short-shaft-isv57t-130s). These work together to provide responsive, high-force motion to the pedal arm.

The base also provides space to mount electronics, including the control and power boards. This build uses the excellent designs by [gilphilbert](https://github.com/gilphilbert) — specifically the V1.1 Power Board and V1.2 Control Board, found here: [DIY-Sim-Racing-FFB-Pedal-PCBs](https://github.com/gilphilbert/DIY-Sim-Racing-FFB-Pedal-PCBs). These boards can be ordered mostly pre-assembled through [JLCPCB](https://jlcpcb.com); see the GitHub repo for full ordering instructions.

### Print Settings

The assembly was printed on a Creality K2 Plus, but your settings will vary depending on the printer and material used. Make sure your filament is well-tuned before printing — the enclosure is large and takes time to complete.

#### Recommended Print Settings

- **Wall loops**: At least 10
- **Top layers**: 12
- **Bottom layers**: 10
- **Infill**: 30% sparse gyroid
- **If using rectangular infill**: Use 40% or higher

⚠️ For nylon:
Thoroughly dry your filament before printing. Even slightly damp nylon will print poorly, resulting in weak layer adhesion and rough surface quality.

Due to the high wall/infill density, use a brim (10mm recommended) and possibly glue stick or other adhesion aid. I used both, and they were necessary to prevent warping.

### Machined Parts

Due to the size and stress this part experiences, it is strongly recommended to machine the base plate from **aluminum or steel** rather than printing it.

For budget-friendly CNC machining, [JLC CNC](https://jlccnc.com) is a solid option. They offer several materials including stainless steel, steel alloy, and aluminum.  
The recommended material is **6061 aluminum** with an **anodized finish**, offering a strong and lightweight plate at a reasonable cost. As of writing, a base plate typically costs **$25–$40 USD** plus shipping.

If machining isn’t an option, the base plate can be 3D printed in plastic. While not ideal, it can work when mounted to a rigid pedal tray or sim rig made from aluminum extrusion (e.g. Trak Racer or Sim-Lab). The printed version is split into **three parts** to accommodate smaller printers.

There are two versions of the rear base file:
- `Base_Rear_V1` — for use with a machined base plate
- `Base_Rear_Alt_V1` — includes additional nut insert support and works with both machined and printed base plates

## Hardware

The hardware used can mostly be sourced from [McMaster-Carr](https://www.mcmaster.com/).  
If you're substituting parts from your local hardware store or Amazon, be sure to double-check dimensions — they’re critical for proper fit and function.

### Hardware List

| **Item** | **Part Number** | **Qty** | **Link** |
|---|---|---|---|
| Linear Rail | JKK60-5-P-150-A1-F4-M / JKK60-10-P-150-A1-F4-M | 1 | [Link](https://jlcmc.com/product/s/B16/BQD-JKK60/FA-%E7%9B%B4%E7%BA%BF%E8%BF%90%E5%8A%A8%E9%9B%B6%E4%BB%B6-%E9%92%A2%E5%88%B6%E7%9B%B4%E7%BA%BF%E6%A8%A1%E7%BB%84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) |
| 130w NEMA 23 Servo Motor | iSV57T-130S | 1 | [Link](https://www.omc-stepperonline.com/nema-23-integrated-easy-servo-motor-130w-3000rpm-0-45nm-63-73oz-in-20-50vdc-servo-motor-short-shaft-isv57t-130s) |
| Gilphilbert Control Board | V1.2 | 1 | [Link](https://github.com/gilphilbert/DIY-Sim-Racing-FFB-Pedal-PCBs/tree/main/control-board) |
| Gilphilbert Power Board | V1.1 | 1 | [Link](https://github.com/gilphilbert/DIY-Sim-Racing-FFB-Pedal-PCBs/tree/main/power-board) |
| FPC FFC PCB Converter Board 6P  | N/A | 1 | [Link](https://a.co/d/bPsciNe) |
| FFC Ribbon Flat Flexible Cable, 6 Pin 0.5mm Pitch 300mm Long | N/A | 1 | [Link](https://a.co/d/6zGifmP) |
| 6 Pin PCIe Extension Cable | N/A | 1 | [Link](https://a.co/d/cVutRBN) |
| 16 Gauge Wire (Various Colors)  | N/A | As needed | [Link](https://a.co/d/feJ6wWT) |
| Kapton Tape | N/A | As needed | [Link](https://a.co/d/9xGHyLZ) |
| USB-C Extension | N/A | 1 | [Link](https://a.co/d/dT4IqKd) |
| XT30 Connector Adapter | N/A | 1 | [Link](https://a.co/d/eTCltLF) |
| JST-XH Connectors | N/A | As needed | [Link](https://a.co/d/135aogA) |
| JST-XH Pin Header Connectors | N/A | 3 x 2-pin, 1 x 3-pin, 1 x 4-pin, 1 x 5-pin | [Link](https://a.co/d/96Qgd40) |
| RG178 U.FL MHF1 to SMA Coax Cable | N/A | 1 | [Link](https://a.co/d/cNCmAZx) |
| 2-pin 0.1" Pitch PCB Screw Terminal Block | N/A | 1  | [Link](https://a.co/d/gwZj4TC) |
| M3x0.5mm Heat Set Insert | 94180A333 | 7 | [Link](https://www.mcmaster.com/94180A333/) |
| M3x0.5 6mm Socket Head Screw | 91292A111 | 8 | [Link](https://www.mcmaster.com/91292A111/) |
| M3x0.5 8mm Flat Head Screw | 92125A128 | 2 | [Link](https://www.mcmaster.com/92125A128/) |
| M3x0.5 16mm Socket Head Screw | 91292A115 | 2 | [Link](https://www.mcmaster.com/91292A115/) |
| M3x0.5 20mm Socket Head Screw | 91292A123 | 2 | [Link](https://www.mcmaster.com/91292A123/) |
| M3x0.5 30mm Socket Head Screw | 91292A022 | 1 | [Link](https://www.mcmaster.com/91292A022/) |
| M4x0.7mm Heat Set Insert | 94180A353 | 14 | [Link](https://www.mcmaster.com/94180A353/) |
| M4x0.7 10mm Flat Head Screw | 92125A190 | 2 | [Link](https://www.mcmaster.com/92125A190/) |
| M4x0.7 16mm Flat Head Screw | 92125A196 | 12 | [Link](https://www.mcmaster.com/92125A196/) |
| M4x0.7 18mm Socket Head Screw | 91292A043 | 4 | [Link](https://www.mcmaster.com/91292A043/) |
| M5x0.8mm Standard Nut | 91828A241 | 6 | [Link](https://www.mcmaster.com/91828A241/) |
| M5x0.8mm Heat Set Insert | 94180A363 | 5 | [Link](https://www.mcmaster.com/94180A363/) |
| M5x0.8 10mm Flat Head Screw | 92125A208 | 1 | [Link](https://www.mcmaster.com/92125A208/) |
| M5x0.8 18mm Socket Head Screw | 91292A127 | 2 | [Link](https://www.mcmaster.com/91292A127/) |
| M5x0.8 35mm Socket Head Screw | 91292A193 | 4 | [Link](https://www.mcmaster.com/91292A193/) |
| M5x0.8 30mm Socket Head Screw | 91292A192 | 4 | [Link](https://www.mcmaster.com/91292A192/) |
| M5 Undersized Washer | 98689A114 | 8 | [Link](https://www.mcmaster.com/98689A114/) |
| Adhesive Silicone Roll | N/A | Optional | [Link](https://a.co/d/0RqzMVF) |

### Notes

1. **Linear Rail** – Use `JKK60-5-P-150-A1-F4-M` for brake pedals. `JKK60-10-P-150-A1-F4-M` can be used for throttle and/or clutch pedals, where faster movement with less force resistance is preferred.
2. **FPC FFC PCB Converter Board 6P** - The complete build includes **2** of these boards so plan your order accordingly.
3. **PCIe Extension Cables** – Each pedal base uses **1** pedal-side PCIe extension cable. The PSU enclosure uses **2** cables with the LRS-350-36 or **3** cables with the LRS-600-36. A 3-pedal / 600w build uses **6** total cables; a 1-pedal / 350w build uses **3** total, and a 2-pedal / 350w build uses **4** total.
4. **Base Plate Hardware** – Use 4 x M5x0.8 35mm Socket Head Screw for a machined base plate. Use 4 x M5x0.8 30mm Socket Head Screw and 4 x M5x0.8mm Standard Nut for a 3D printed base plate.

## Assembly

A complete walkthrough of the assembly process can be found on the [Wiki](https://github.com/chrisjameschamp/DIY-Active-Pedal-Design/wiki/05-%E2%80%90-Pedal-Base)

## License

These 3D design files are licensed under a [Creative Commons BY-NC-SA 4.0 License](https://creativecommons.org/licenses/by-nc-sa/4.0/).

You may:
- Use and remix these files for **personal, non-commercial purposes**.
- Share modified versions, as long as they are also non-commercial, include credit, and use the **same license**.

You may NOT:
- Use these files or derivatives **for commercial use**.
- Re-license modified versions under more restrictive or proprietary terms.

Please credit **@ChrisJamesChamp** and link back to this repository if you use, remix, or share these designs.

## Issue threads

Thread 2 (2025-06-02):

Load Cell Model

oO-OniZuk4-Oo, 2025-06-02:
Hi,

I'm sorry but I don't see the load cell model in the hardware list.
I think is the YZC-516C in 200kg, but not sure.

Thx !

chrisjameschamp, 2025-06-02:
You are correct, it looks like I am missing that, there are a few things missing from my hardware list that I need to update.  I will do so in the next few days.

Here is the part number for the Loadcell

 	DYLY-107 200kg variant

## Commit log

2025-03-23 Added the Pedal Arm
    [Pedal_Arm_Brackets_V2.stl, Pedal_Arm_V2.stl]
2025-03-23 Updated Pedal Arm README
2025-04-01 Added design files for the Power Supply Enclosure
    [PSU_Case_V1.stl, PSU_IoCover_V1.stl]
2025-04-01 Added Split PSU Case Files
    [PSU_Case_Front_V1.stl, PSU_Case_Rear_V1.stl]
2025-04-14 Added a 350w Power Supply Option
    [350w_PSU_Case_Front_V1.stl, 350w_PSU_Case_Rear_V1.stl, 350w_PSU_Case_V1.stl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]
2025-04-18 Added Base Assembly Files
    [Base_Front_V1.stl, Base_IO_Bracket_V1.stl, Base_PCB_Cover_V1.stl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]
2025-04-18 Updated Readme for Power Supplys and Base Assembly
2025-04-18 Update Base Assembly Readme
2025-04-28 Added the Slider design files
    [Slider_Base_V1.stl, Slider_Mount_V1.stl, Slider_MountwPCB_V1.stl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]
2025-04-28 Added the Cover design files
    [Cover_Front_V1.stl, Cover_Rear_V1.stl, Cover_V1.step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]
2025-04-29 Updated parts list an image for the Pedal Arm
2025-04-29 Fixed size of the Pedal Arm Image
2025-04-29 Added the Load Cell Arm
    [Load_Cell_Arm_V1.step, Load_Cell_Arm_V1.stl]
2025-04-29 Added the Pedal Faces
    [BrakeClutch_Beauty_Ring_V1.stl, BrakeClutch_Pedal_Face_V1.stl, Brake_Mounting_Bracket_V1.stl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]
2025-04-29 Added the Pedal Arm Lower Brackets
    [Pedal_Arm_Lower_Brackets_V2.stl, Pedal_Arm_Upper_Brackets_V2.stl]
2026-06-03 Update design documentation and pedal arm files
    [Pedal_Arm_Upper_Brackets_V2.stl, Pedal_Arm_V2.step, Pedal_Arm_V2.stl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]
2026-06-03 Point README to numbered wiki landing page

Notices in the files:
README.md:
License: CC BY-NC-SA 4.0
